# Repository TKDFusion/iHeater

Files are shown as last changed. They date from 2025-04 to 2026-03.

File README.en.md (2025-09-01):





# About the iHeater Project

iHeater is a compact and powerful solution for creating an active thermal chamber in any 3D printer. It is especially essential for printers with closed or proprietary electronics, such as those from Creality, Bambu Lab, and FlashForge, where available ports or options for connecting heaters, fans, and thermistors are often limited.

iHeater connects via USB and takes over control independently of the mainboard's limitations. Depending on the firmware used, it can operate autonomously or with full integration into Klipper.

When used in combination with bed heating, iHeater ensures uniform chamber heating-a crucial factor for printing materials like ABS, PA, PC, and other engineering plastics. The device dynamically manages heating based on the air temperature, creating stable conditions inside the chamber without overheating or temperature spikes.

Two versions are currently available:

* 100W for smaller printers (archived)
* 200W for larger printers

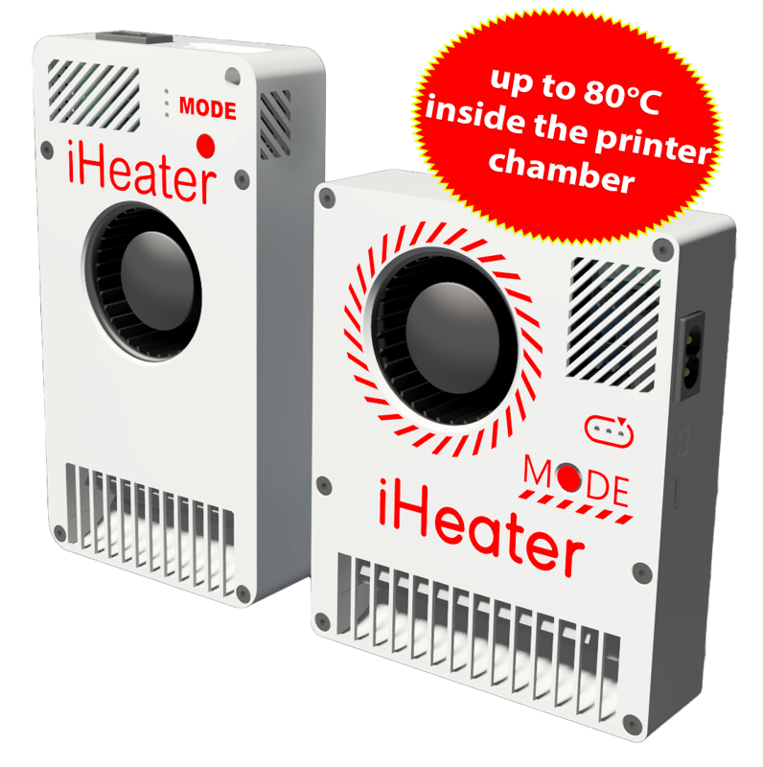
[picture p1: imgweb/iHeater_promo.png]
iHeater


**Under Klipper Control**

The board works as a separate MCU in Klipper, fully autonomously controlling the chamber heater and fan. Thanks to its 220 V power supply, iHeater does not load the printer’s power supply, which is especially important since stock PSUs often operate at their limit.

The cost of the board is comparable to or even lower than building a similar solution from a regular microcontroller, solid-state relay, and other components. Nevertheless, enthusiasts still have the option to build their own version.

iHeater is a simple way to add chamber heating to your printer to improve print quality and expand the range of materials used.

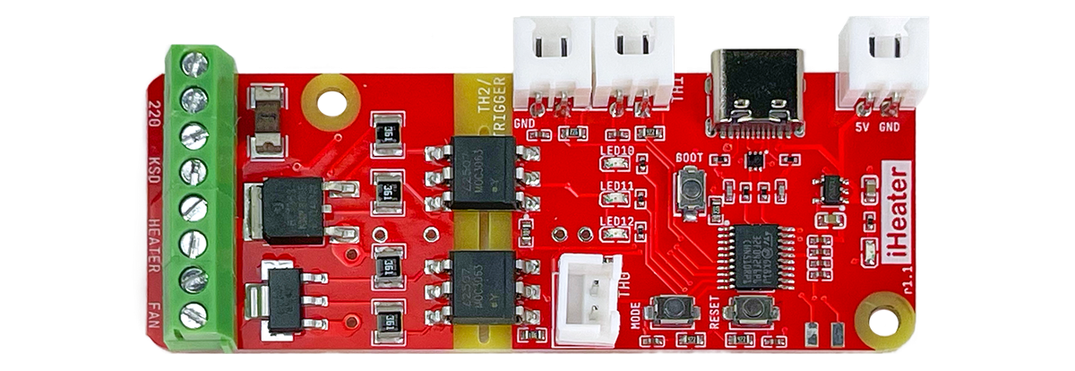
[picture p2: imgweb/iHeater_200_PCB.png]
PCB


**With iHeater Firmware**



The iHeater board is self-sufficient and includes all the necessary peripherals and interface for use as a standalone device. The desired temperature is set by sequentially pressing the MODE button, and the selected temperature is encoded and displayed using three LEDs. The increment can be changed in the firmware.

<!-- 
# iHeater Configuration for Klipper

This repository contains configuration files for the iHeater 3D printer chamber heater based on Klipper firmware and the control board of the same name. The configuration is designed to control the chamber heater and fans using the iHeater microcontroller.

## Table of Contents

- [Requirements](#requirements)
- [Preparation](#preparation)
- [Flashing Firmware to iHeater](#flashing-firmware-to-iheater)
- [Klipper Configuration](#klipper-configuration)
  - [Connecting the `iHeater` MCU](#1-connecting-the-iheater-mcu)
- [Usage](#usage)
  - [Chamber Heating Commands](#chamber-heating-commands)
  - [Automation and Control Logic](#automation-and-control-logic)
- [Notes](#notes)
- [License](#license)

## Requirements

- **Hardware:**
  - iHeater control board
  - NTC 100K 3950 thermistors (2 pcs.)
  - PTC heating element 220V 100W for the chamber
  - 7530 fan 220V for chamber air circulation
  - Thermal fuse KSD9700 or similar (220V 5A 130°C)

- **Software:**
  - Klipper (latest version)
  - A configured and running Klipper host

## Preparation

1. **Assemble the hardware:**
   - Connect the heating element and fans to the iHeater.
   - Connect the KSD to the appropriate socket.
   - Install the thermistors in the chamber and connect them to the appropriate MCU pins.
   - Make sure the pins are connected correctly according to the config file.

2. **Install the required files:**
   - Copy the `iHeater.cfg` file to the Klipper configuration directory.

## Flashing Firmware to iHeater

1. **Build the Klipper firmware for stm32f042:**

```bash
cd klipper/
make menuconfig
```

2. **In the menu, select:**

- Enable extra low-level configuration options  
- Micro-controller Architecture: STMicroelectronics STM32  
- Processor model: STM32F042  
- Bootloader offset: 8KiB bootloader  
- Clock Reference: Internal clock  
- Communication interface: USB (on PA9/PA10)

3. **Disable unnecessary options:**

```text
[*] Support GPIO "bit-banging" devices  
[ ] Support LCD devices  
[ ] Support thermocouple MAX sensors  
[ ] Support adxl accelerometers  
[ ] Support lis2dw and lis3dh 3-axis accelerometers  
[ ] Support MPU accelerometers  
[ ] Support HX711 and HX717 ADC chips  
[ ] Support ADS 1220 ADC chip  
[ ] Support ldc1612 eddy current sensor  
[ ] Support angle sensors  
[*] Support software based I2C "bit-banging"  
[ ] Support software based SPI "bit-banging"
```

4. Save and exit the menu.

5. Compile the firmware:

```bash
make clean
make
```

Expected output:

```
Creating hex file out/klipper.bin
```

6. Flash the firmware to the iHeater board:

If needed, install python3-serial:

```bash
sudo apt install python3-serial
```

**The following assumes the Katapult bootloader is installed.**

- Connect iHeater to the host in programming mode (hold the Mode button while connecting or double-press RESET).
- Find the device:

```bash
ls /dev/serial/by-id/
```

Expected result:

```
usb-katapult_stm32f042x6_0C0018000D53304347373020-if00
```

- Replace with your device ID and run:

```bash
python3 ~/katapult/scripts/flashtool.py -d /dev/serial/by-id/usb-katapult_stm32f042x6_... -f ~/klipper/out/klipper.bin
```

Expected result:

```
Flash Success
```

- Verify:

```bash
ls /dev/serial/by-id/
```

Expected:

```
usb-Klipper_stm32f042x6_...-if00
```

```text
iHeater is ready to work with Klipper
```

## Pin Configuration

| Pin  | Alias | Function |
|---|---|---|
| PA0  | TH1 | Chamber temperature sensor |
| PA1  | HEATER| Heater control |
| PA2  | FAN | Fan control |
| PA3  | TH0 | Heater temperature sensor |
| PA4  | MODE  | Mode button |
| PA5  | LED3  | LED 3 |
| PA6  | LED2  | LED 2 |
| PA7  | LED1  | LED 1 |

## Klipper Configuration

Copy the iHeater.cfg file to the folder containing printer.cfg and include it using the `[include]` directive:

```ini
[include iHeater.cfg]
```

### 1. Connecting the iHeater MCU

Edit the `iHeater.cfg` file and specify the obtained serial ID:

```ini
[mcu iHeater]
serial: usb-Klipper_stm32f042x6_0C0018000D53304347373020-if000
```

## Usage

### Chamber Heating Commands

- Set chamber temperature:

```gcode
M141 S60 ; Set chamber temp to 60°C
```

- Wait for chamber to reach temperature:

```gcode
M191 S60 ; Wait until chamber reaches 60°C
```

- Stop chamber heating:

```gcode
M141 S0  ; Disable chamber heating
```

- At the end of your slicer’s G-code, add `M141 S0` to properly shut down chamber heating.

## Notes

- **Safety:**
  - Make sure all connections are correct and safe.
  - Check that min_temp and max_temp match your hardware specs.

- **Hardware check:**
  - Test heater and fan operation before use.
  - Monitor temperature during first runs.

- **PID tuning:**
  - Perform PID tuning if precise temperature control is needed. -->

## License

This project is licensed under the MIT License. See the [LICENSE](./license.en.md) file for details.

>⚠️ **Warning: The use of heating elements and temperature control involves fire and equipment damage risk. Always follow manufacturer recommendations and observe safety precautions.

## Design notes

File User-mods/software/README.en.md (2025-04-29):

# Here is list of users software mods and articles

_Place your mod name and short description to the list below.
Please keep alphabetical ordering_

  * WSL2_Ubuntu_FF (RU) - Как прошить устройство из под Windows 10/11 используя WSL2 с работающей на ней Ubuntu 20.04 (How to flash iHeater/Katapult/Klipper firmware on Windows 10/11 using WSL2 with Ubuntu 20.04 guest OS)

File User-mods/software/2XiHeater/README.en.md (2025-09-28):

Controls two iHeaters in tandem to achieve a target chamber temperatur, adding smart LED controls:
  LEFT: Fan status
  CENTER: Target temperature set
  RIGHT: Heater active (power >30%)
I've also added logic to check if iHeater has AC power. If not, it will kill the heat up process.

Based on the original single iHeater.cfg

I tested on my SV08 MAX. LED controls are not perfect, since the SV08 MAX doesn't have the latest version of Klipper so we cannot do duplicate_pin for correct heater / fan activity indicators.
I do a 2:1 weighted average for the two chamber thermistors, one in the designated hole on the back panel, the other moves around attached to the center of the gantry...
Please refer to my video on YouTube for my arrangement of the two iHeaters: https://www.youtube.com/watch?v=KfKujRUKnWg

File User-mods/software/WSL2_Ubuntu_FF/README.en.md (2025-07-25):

# How to Flash a Device on Windows 10/11 Using WSL2 with Ubuntu 20.04

## Steps 1-10 are suitable for flashing:

* Standalone Firmware
* Katapult Bootloader (for later flashing of the Klipper runtime from the printer host)
* Klipper runtime without using Katapult

It is assumed the firmware is already compiled and located on the WSL guest system at `~/iHeater/firmware.bin`

> [!NOTE] At the beginning of each step, brackets indicate where to perform the action: [WIN] - in native Windows, [WSL] - in the guest OS terminal (Ubuntu)

1. **[WIN]** Follow [this guide](https://learn.microsoft.com/en-us/windows/wsl/connect-usb) to install USBIPD-WIN from the [releases page](https://github.com/dorssel/usbipd-win/releases)

2. **[WSL]** Ensure WSL is active (simply start a command-line session in the guest OS)

3. **[WIN]** Connect the device to the PC (ensure the BOOT jumper is installed during connection)

   > [!NOTE] Note that a clean chip (never previously flashed) automatically enters DFU mode without a jumper.

4. **[WIN]** Open Windows PowerShell **as administrator** and enter:

    ```
    > usbipd list
    BUSID  VID:PID    DEVICE                                                        STATE
    5-2    0483:df11  STM32  BOOTLOADER                                             Not shared
    ```

   Remember the BUSID value

5. **[WIN]** Enter the command with the recorded BUSID

   > [!NOTE] This command is necessary if the last column shows `Not shared` (e.g., after flashing Klipper)

   ```
   > usbipd bind --busid 5-2
   ```

   Repeat the command from step 4 to confirm the STATE column shows "Shared"

   ```
   > usbipd list
   Connected:
   BUSID  VID:PID    DEVICE                                                        STATE
   5-2    0483:df11  STM32  BOOTLOADER                                             Shared
   ```

6. **[WIN]** Attach the device to the guest OS (replace `busid` with your actual value):

   ```
   > usbipd attach --wsl --busid 5-2
   ```

   > [!NOTE] This command must be run each time the device is reconnected/rebooted, but can be executed from PowerShell without administrator rights

   The device will then "disconnect" from Windows and attach to the guest OS.

   Verify the device is attached using the command from step 4 (STATE should be `Attached`)

   ```
   > usbipd list
   Connected:
   BUSID  VID:PID    DEVICE                                                        STATE
   5-2    0483:df11  STM32  BOOTLOADER                                             Attached
   ```

7. **[WSL]** In the guest OS, verify device presence with:

   ```
   > lsusb
   Bus 001 Device 006: ID 0483:df11 STMicroelectronics STM Device in DFU Mode
   ```

8. **[WSL]** Install the utility in the guest OS

   ```
   > sudo apt install dfu-util
   ```

9. **[WSL]** Ensure the board is in DFU mode and visible to dfu-util:

   ```
   > sudo dfu-util --list
   ```

10. **[WSL]** Flash the firmware

    ```
    > sudo dfu-util -a 0 -s 0x08000000 -D ~/iHeater/firmware.bin
    ```

## Further Steps - If You Wish to Compile and Flash the Klipper Runtime from WSL (Instead of the Printer Host)

Assuming the firmware is already compiled (as per the official guide) and located at `~/iHeater/klipper.bin`

11. **[WIN]** Reconnect the device (unplug/plug USB) while holding the MODE button. LED3 should start blinking slowly, indicating Katapult is ready to receive the firmware. Release the button.

12. **[WIN]+** **[WSL]** Repeat steps 4-7 (step 5 can likely be skipped—see note therein). The command in step 7 should now show:

    ```
    > lsusb
    Bus 001 Device 005: ID 1d50:6177 OpenMoko, Inc. stm32f042x6
    ```

    This indicates the device name has changed.

13. **[WSL]** The command `ls /dev/serial/by-id/` may return nothing, since the connected board appears as a standard USB-CDC-ACM device.

    To verify, use:

    ```
    > dmesg
    ```

    **Note - In the example, the last line shows "ttyACM0" - this is the device "address".**

14. **[WSL]** Flash the device (with sudo). Ensure paths are correct:

    ```
    > sudo python3 ~/katapult/scripts/flashtool.py -d /dev/ttyACM0 -b 250000 -f ~/iHeater/klipper.bin
    ```

That’s it - you can now connect the board to the printer and proceed with configuration per the documentation.

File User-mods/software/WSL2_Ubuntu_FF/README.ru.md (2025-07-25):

# WSL

## Как прошить устройство из под Windows 10/11 используя WSL2 с работающей на ней Ubuntu 20.04

## Пункты 1-10 подходят для прошивки:
- Standalone Firmware
- Загрузчика Katapult (для последующей заливки управляемой части Klipper уже с хоста самого принтера)
- Управляемой части Klipper без использования Katapult

Предполагается что прошивка уже скомпилирована и находится на гостевой системе WSL по пути `~/iHeater/firmware.bin`

> [!NOTE] В начале каждого пункта в квадратных скобках указано где именно проводить указанные действия: [WIN] - в самом Windows, [WSL] - в терминале гостевой ОС (Ubuntu)

1. **[WIN]** Следуя вот [этой инструкции](https://learn.microsoft.com/en-us/windows/wsl/connect-usb) установить USBIPD-WIN со [страницы релизов](https://github.com/dorssel/usbipd-win/releases)

2. **[WSL]** Убедиться что WSL активен (достаточно просто запустить сеанс командной строки гостевой ОС)

3. **[WIN]** Подключаем устройство к ПК (убедитесь что при подключении установлена перемычка BOOT)

    > [!NOTE] Обратите внимание, что чистый чип (ранее не прошивавшийся) автоматически переходит в режим DFU без перемычки.

4. **[WIN]** Открываем Windows PowerShell **в режиме администратора** и вводим

    ```
    > usbipd list
    BUSID  VID:PID    DEVICE                                                        STATE
    5-2    0483:df11  STM32  BOOTLOADER                                             Not shared
    ```
    Запоминаем значение в колоке BUSID

5. **[WIN]** Вводим команду с подстановкой запомненного BUSID

    > [!NOTE] Эта команда нужна в том случае, если в последнем столбце появляется `Not shared` (например после прошивки клиппера)

    ```
    > usbipd bind --busid 5-2
    ```

    повторяем команду из п.4 чтобы убедиться что в столбце STATE для нашего устройства указано "Shared"

    ```
    > usbipd list
    Connected:
    BUSID  VID:PID    DEVICE                                                        STATE
    5-2    0483:df11  STM32  BOOTLOADER                                             Shared
    ```

6. **[WIN]** Прицепляем устройство в гостевую ОС (не забываем заменить значение для `busid` на свой):

    ```
    > usbipd attach --wsl --busid 5-2
    ```
    > [!NOTE]Данную команду данную комманду нужно вводить каждый раз, когда переподключаете/перезагружаете устройство, но делать это уже можно в Power Shell без прав администратора

    При этом устройство "отключиться" от Windows и подключится внутрь гостевой ОС.

    Проверяем что устройство прицепилось используя команду из п.4 (в столбце STATE должно быть написано `Attached`)

    ```
    > usbipd list
    Connected:
    BUSID  VID:PID    DEVICE                                                        STATE
    5-2    0483:df11  STM32  BOOTLOADER                                             Attached
    ```

7. **[WSL]** В гостевой ОС проверяем наличие устройства командой `lsusb`

    ```
    > lsusb
    Bus 001 Device 006: ID 0483:df11 STMicroelectronics STM Device in DFU Mode
    ```

8. **[WSL]** Устанавливаем на гостевую ОС утилиту

    ```
    > sudo apt install dfu-util
    ```

9. **[WSL]** Убедитесь что подключенная плата в режиме DFU и dfu-util ее видит (в квадратных скобках будет идентификатор устройства, который было видно так же в пп.4-7)

    ```
    > sudo dfu-util --list

    dfu-util 0.9

    Copyright 2005-2009 Weston Schmidt, Harald Welte and OpenMoko Inc.
    Copyright 2010-2016 Tormod Volden and Stefan Schmidt
    This program is Free Software and has ABSOLUTELY NO WARRANTY
    Please report bugs to http://sourceforge.net/p/dfu-util/tickets/

    Found DFU: [0483:df11] ver=2200, devnum=10, cfg=1, intf=0, path="1-1", alt=1, name="@Option Bytes  /0x1FFFF800/01*016 e", serial="FFFFFFFEFFFF"
    Found DFU: [0483:df11] ver=2200, devnum=10, cfg=1, intf=0, path="1-1", alt=0, name="@Internal Flash  /0x08000000/032*0001Kg", serial="FFFFFFFEFFFF"
    ```

10. **[WSL]** Прошиваем

    ```
    > sudo dfu-util -a 0 -s 0x08000000 -D ~/iHeater/firmware.bin

    dfu-util 0.9

    Copyright 2005-2009 Weston Schmidt, Harald Welte and OpenMoko Inc.
    Copyright 2010-2016 Tormod Volden and Stefan Schmidt
    This program is Free Software and has ABSOLUTELY NO WARRANTY
    Please report bugs to http://sourceforge.net/p/dfu-util/tickets/

    dfu-util: Invalid DFU suffix signature
    dfu-util: A valid DFU suffix will be required in a future dfu-util release!!!
    Opening DFU capable USB device...
    ID 0483:df11
    Run-time device DFU version 011a
    Claiming USB DFU Interface...
    Setting Alternate Setting #0 ...
    Determining device status: state = dfuERROR, status = 10
    dfuERROR, clearing status
    Determining device status: state = dfuIDLE, status = 0
    dfuIDLE, continuing
    DFU mode device DFU version 011a
    Device returned transfer size 2048
    DfuSe interface name: "Internal Flash  "
    Downloading to address = 0x08000000, size = 24252
    Download        [=========================] 100%        24252 bytes
    Download done.
    File downloaded successfully
    ```

## Следующие шаги - если хочется скомпилировать и прошить управляемую часть Klipper также из под WSL (то есть не с хоста принтера).

Допустим вы скомпилировали уже прошивку (согласно инструкции в документации) и теперь она у вас лежит в `~/iHeater/klipper.bin`

11. **[WIN]** Переподключаем устройство к ПК (USB-шнурок отключить-поодключить) с зажатой кнопкой MODE .
При этом должен начать медленно мигать LED3 - это значит что Katapult перешла в режим ожидания получения прошивки (аналог DFU-режима) и кнопку можно отпустить.

12. **[WIN]**+**[WSL]** Повторяем пп.4-7 (п.5 скорее всего можно пропустить - см. в нем пояснения)
при этом команда из п.7 покажет что-то вроде:

    ```
    > lsusb
    Bus 001 Device 005: ID 1d50:6177 OpenMoko, Inc. stm32f042x6
    ```
    То есть название устройства изменилось.

13. **[WSL]** В WSL команда ls /dev/serial/by-id/ скорее всего не даст результата, так как подключенная плата появится там в виде стандартного устройства USB-CDC-ACM

    Проверить это можно введя команду
    ```
    > dmesg

    [53229.047396] vhci_hcd vhci_hcd.0: pdev(0) rhport(0) sockfd(3)
    [53229.048526] vhci_hcd vhci_hcd.0: devid(327682) speed(2) speed_str(full-speed)
    [53229.049243] vhci_hcd vhci_hcd.0: Device attached
    [53229.321619] vhci_hcd: vhci_device speed not set
    [53229.391684] usb 1-1: new full-speed USB device number 7 using vhci_hcd
    [53229.471650] vhci_hcd: vhci_device speed not set
    [53229.541609] usb 1-1: SetAddress Request (7) to port 0
    [53229.579674] usb 1-1: New USB device found, idVendor=1d50, idProduct=6177, bcdDevice= 1.00
    [53229.580696] usb 1-1: New USB device strings: Mfr=1, Product=2, SerialNumber=3
    [53229.581508] usb 1-1: Product: stm32f042x6
    [53229.581982] usb 1-1: Manufacturer: katapult
    [53229.582912] usb 1-1: SerialNumber: 460024000E53304347373020
    [53229.586466] cdc_acm 1-1:1.0: ttyACM0: USB ACM device
    ```
    
    **Обратите внимание - в примере в последней строчке указан "ttyACM0" - это и есть "адрес" устройства.**

14. **[WSL]** Прошиваем устройство (под sudoб то есть правами суперпользователя)
не забываем проверить и при необходимости поправить пути

    ```
    > sudo python3 ~/katapult/scripts/flashtool.py -d /dev/ttyACM0 -b 250000 -f ~/iHeater/klipper.bin

    Connecting to Serial Device /dev/ttyACM0, baud 250000
    Detected USB device running Katapult
    Detected Klipper binary version v0.13.0-51-gbfda326c2, MCU: stm32f042x6
    Attempting to connect to bootloader
    Katapult Connected
    Software Version: v0.0.1-96-gbc1ecea
    Protocol Version: 1.1.0
    Block Size: 64 bytes
    Application Start: 0x8002000
    MCU type: stm32f042x6
    Flashing '/home/kekht/iHeater/klipper_vanilla/klipper.bin'...

    [##################################################]

    Write complete: 14 pages
    Verifying (block count = 213)...

    [##################################################]

    Verification Complete: SHA = 3C7153502764CB6C948E9FD7872F69B2D0CBED55
    Programming Complete
    ```

Вот и все, теперь можно подключать к принтеру и настраивать согласно документации.

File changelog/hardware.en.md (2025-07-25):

Rev 1.1

- Добавлен третий термистор - используется как триггер включения iHeater: нагрев включается при температуре выше 60 °C, отключается при снижении температуры стола до устойчиво низкого уровня. Реализовано в поддержку пользователей Standalone-прошивки.

- Обновлена топология платы - улучшено размещение компонентов и трассировка.

- Изменён способ подключения питания - основной вариант: кабель питания вводится через кабельный ввод в стенке корпуса и подключается в винтовые клеммы. Позволяет делать удобный монтаж с коммутацией питания через основную линию питания принтера. Альтернативный способ: разъём C8 устанавливается на корпус. Плату можно ориентировать произвольно.

- Pin to pin совместимо с текущей версией кроме поддержки третьего термистора.

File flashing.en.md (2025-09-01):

# Firmware

This document provides instructions for building and flashing the **Katapult** bootloader for the **iHeater** microcontroller. The Katapult bootloader enables flashing Klipper firmware via USB and includes guidance on flashing **Klipper** firmware onto the **iHeater** controller.

---

## Requirements

* STM32F042F6P6
* iHeater board
* USB cable
* Linux system (e.g., Raspberry Pi or 3D printer)

!!! warning "If you cannot build and flash firmware on the printer"
    [Refer to the WSL section](./User-mods/software/WSL2_Ubuntu_FF/README.en.md)

---

## Building Katapult

1. Clone the Katapult repository:

```bash
git clone https://github.com/Arksine/katapult.git
cd katapult
make menuconfig
```

2. In `menuconfig`, select:

<!-- - MCU Architecture: STM32
- Processor model: STM32F042
- Clock Reference: Internal
- Communication interface: USB (on PA9/PA10)
- Application start offset: **8KiB offset**
- [x] Support bootloader entry on rapid double click of reset button
- [x] Enable bootloader entry on button (or gpio) state
- (!PA4)  Button GPIO Pin
- [X] Enable Status LED
- (PA5)   Status LED GPIO Pin -->

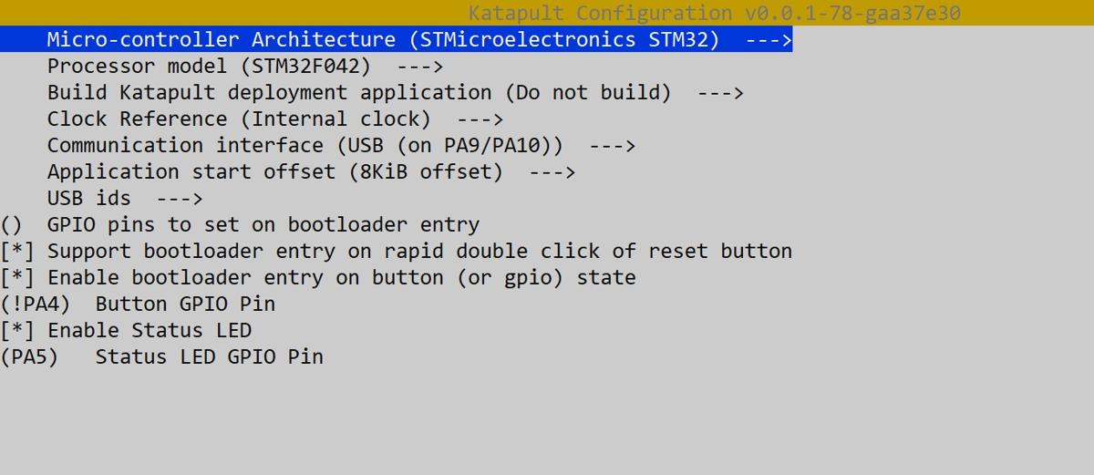
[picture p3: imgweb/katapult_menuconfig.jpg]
menuconfig


3. Build the firmware:

```bash
make
```

The firmware will be created in `out/katapult.bin`.

---

## Flashing Katapult via DFU

> This step is only needed once to install Katapult.

### Preparation:

Install `dfu-util` if it is not already installed:

```bash
sudo apt install dfu-util
```

According to the board version:

=== "r1"

    Set the jumper to BOOT0 and power cycle the board (or press the RESET button).
    The microcontroller will boot into DFU mode.

=== "r1.1"

    Press and hold BOOT, then power cycle the board (or press the RESET button), and release BOOT.
    The microcontroller will boot into DFU mode.

Check the connection:

```bash
lsusb
```

You should see:

```
ID 0483:df11 STMicroelectronics STM Device in DFU Mode
```

### Flash Katapult:

Put it in DFU mode.

Run the command:

```bash
dfu-util -a 0 -D out/katapult.bin -s 0x08000000:leave
```

Example of successful flashing:

```
Downloading to address = 0x08000000, size = 4968
Download        [=========================] 100%         4968 bytes
Download done.
File downloaded successfully
Transitioning to dfuMANIFEST state
```

Exit DFU mode.

After reboot:

```bash
ls /dev/serial/by-id/*
```

You should see:

```
/dev/serial/by-id/usb-katapult_stm32f042x6_XXXXXXXXXXXXXX-if00
```

If there are permission issues when flashing, run:

```bash
sudo chmod 777 /dev/serial/by-id/usb-katapult_stm32f042x6_XXXXXXXXXXXXXX-if00
```

!!! warning "if something went wrong"
    erase the memory of the MCU and repeat the previous steps
    ```
    touch /tmp/empty.bin
    ```
    ```
    dfu-util -a 0 -d 0483:df11 -s :mass-erase:force -D /tmp/empty.bin
    ```

### Notes

* Katapult uses the first 8 KiB of flash, so **set 8 KiB bootloader offset in Klipper**.
* DFU mode can be entered using either a double Reset or a button on GPIO (PA4).
* If PA13/PA14 are used for SWD.
* Once Katapult is flashed, ST-Link is no longer needed - all further work is done via USB.

---

## Flashing Klipper to iHeater

### Compile the firmware:

```bash
cd ~/klipper
```

```
make menuconfig
```

#### In the menu, select:

```
Enable extra low-level configuration options

Micro-controller Architecture (STMicroelectronics STM32)

Processor model (STM32F042)

Bootloader offset (8KiB bootloader)

Clock Reference (Internal clock)

Communication interface (USB (on PA9/PA10))
```

#### Disable all unnecessary options:

```
[*] Support micro-controller based ADC (analog to digital)
[ ] Support communicating with external chips via SPI bus
[ ] Support communicating with external chips via I2C bus
[*] Support GPIO based button reading
[ ] Support Trinamic stepper motor driver UART communication
[ ] Support 'neopixel' type LED control
[ ] Support measuring fan tachometer GPIO pins
    *** LCD chips ***
[ ] Support ST7920 LCD display
[ ] Support HD44780 LCD display
    *** External ADC type chips ***
[ ] Support HX711 and HX717 ADC chips
```

#### Save and exit the menu.

#### Build the firmware:

```bash
make clean
make
```

!!! Result should look like:
    Creating hex file out/klipper.bin

### Flash firmware to the iHeater board

!!! note "Install python3-serial if needed"
    sudo apt install python3-serial

**The following assumes Katapult bootloader is already installed**

* Connect the iHeater to the host in programming mode (hold the MODE button during connection or double-press RESET).

* List serial devices:

```bash
ls /dev/serial/by-id/
```

Example output:

```
usb-katapult_stm32f042x6_0C0018000D53304347373020-if00
```

* Install flashtool if needed:

```bash
pip install flashtool
```

* Replace the ID with your actual ID and run:

```bash
python3 ~/katapult/scripts/flashtool.py -d /dev/serial/by-id/usb-katapult_stm32f042x6_0C0018000D53304347373020-if00 -f ~/klipper/out/klipper.bin
```

Expected output:

```
Flashing '/home/pi/klipper/out/klipper.bin'...

[##################################################]

Write complete: 20 pages

Verifying (block count = 319)...

[##################################################]

Verification Complete: SHA = 8A3DDF39A0E70B684DC6BAF74EF8F089EBDD6C18

Flash Success
```

* Verify:

```bash
ls /dev/serial/by-id/
```

Expected output:

```
usb-Klipper_stm32f042x6_0C0018000D53304347373020-if00
```

`iHeater is ready to work with Klipper`

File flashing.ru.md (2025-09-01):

#  Прошивка

Этот документ содержит инструкции по сборке и прошивке загрузчика **Katapult** для микроконтроллера **iHeater**. Загрузчик Katapult позволяет прошивать прошивку Klipper по USB, а так же содержит документацию по установке прошивки **Klipper** на контроллер **iHeater** 

---

## Что потребуется

- STM32F042F6P6
- Плата iHeater
- USB кабель
- Linux-система (например, Raspberry Pi или принтер)

!!! warning "Если нет возможности собрать и прошить прошивку на принтере"
    [Обратитесь к разделу WSL](../iHeater/User-mods/software/WSL2_Ubuntu_FF/README.ru.md)

---

## Сборка Katapult

1. Клонировать репозиторий Katapult:

```bash
git clone https://github.com/Arksine/katapult.git
```
```
cd katapult
```
```
make menuconfig
```

2. В `menuconfig` выбрать:

menuconfig

3. Сборка:

```bash
make
```

Прошивка будет создана в `out/katapult.bin`.

---

## Прошивка Katapult через DFU

> Этот шаг нужен только один раз, для загрузки самого Katapult.

### Подготовка:
Устновить утилиту dfu-util, если она ещё не установлена:
    
    sudo apt install dfu-util

В соответствии с версией платы:

=== "r1"

    Установить джампер на BOOT0 и перезапустить питание платы (или нажать кнопку RESET).
    Микроконтроллер загрузится в режим DFU.

=== "r1.1"

    Нажать кнопку BOOT и перезапустить питание платы (или нажми кнопку RESET) отпустить BOOT.
    Микроконтроллер загрузится в режим DFU.

Проверить подключение:

    lsusb

Результат:

    ID 0483:df11 STMicroelectronics STM Device in DFU Mode

### Прошивка Katapult:
Перевести в режим DFU.

Выполнить команду:

```
dfu-util -a 0 -D out/katapult.bin -s 0x08000000:leave
```

Пример успешной прошивки:

```
Downloading to address = 0x08000000, size = 4968
Download        [=========================] 100%         4968 bytes
Download done.
File downloaded successfully
Transitioning to dfuMANIFEST state
```

Выйти из режима DFU.

После перезапуска 
```
ls /dev/serial/by-id/*
```
Результат:
```
/dev/serial/by-id/usb-katapult_stm32f042x6_XXXXXXXXXXXXXX-if00
```

Если нет прав, возможны ошибки при прошивке, чтобы получить доступ выполнить команду:
```
sudo chmod 777 /dev/serial/by-id/usb-katapult_stm32f042x6_XXXXXXXXXXXXXX-if00
``` 

!!! warning "если что-то пошло не так"
    затрите память МК и повторите предыдущие шаги
    ```
    touch /tmp/empty.bin
    ```
    ```
    dfu-util -a 0 -d 0483:df11 -s :mass-erase:force -D /tmp/empty.bin
    ```

### Примечания

- Katapult занимает первые 8 КБ Flash, поэтому **в Klipper обязательно указывать смещение 8 KiB**.
- Можно использовать либо двойной Reset, либо кнопку на GPIO (PA4) для входа в DFU.
- Если PA13/PA14 используются для SWD
- После прошивки Katapult можно больше не использовать ST-Link - вся дальнейшая работа по USB.

## Установка прошивки на iHeater

### Компиляция прошивки
```
cd ~/klipper
```
```
make menuconfig
```

#### В меню конфигурации выбрать
```
Enable extra low-level configuration options

Micro-controller Architecture (STMicroelectronics STM32)

Processor model (STM32F042)

Bootloader offset (8KiB bootloader)

Clock Reference (Internal clock)

Communication interface (USB (on PA9/PA10))
```
#### Выключить все лишнее
```
[*] Support micro-controller based ADC (analog to digital)
[ ] Support communicating with external chips via SPI bus
[ ] Support communicating with external chips via I2C bus
[*] Support GPIO based button reading
[ ] Support Trinamic stepper motor driver UART communication
[ ] Support 'neopixel' type LED control
[ ] Support measuring fan tachometer GPIO pins
    *** LCD chips ***
[ ] Support ST7920 LCD display
[ ] Support HD44780 LCD display
    *** External ADC type chips ***
[ ] Support HX711 and HX717 ADC chips
```

#### Сохранить и выйти из меню.

#### Скомпилировать прошивку
```
make clean
```
```
make
```

Результат:

    Creating hex file out/klipper.bin

### Установка прошивки на плату iHeater

!!! note "Может потребоваться установка python3-serial"
    
    sudo apt install python3-serial

**Далее рассматривается вариант установки с установленным бутлоадером Katapult**

- Подключить iHeater к хосту в режиме программирования (удерживая кнопку Mode при подключении или дважды нажав RESET).

- Выполнить поиск 
    ```
    ls /dev/serial/by-id/
    ```
    Результат должен выглядеть так:

    ```
    usb-katapult_stm32f042x6_0C0018000D53304347373020-if00
    ```

    - При необходимости установить flashtool

    ```
    pip install flashtool
    ```

- Изменить на свой ID и введите:
    
        python3 ~/katapult/scripts/flashtool.py -d /dev/serial/by-id/usb-katapult_stm32f042x6_0C0018000D53304347373020-if00 -f ~/klipper/out/klipper.bin

    Результат:

        Flashing '/home/pi/klipper/out/klipper.bin'...

        [##################################################]
        
        Write complete: 20 pages
        
        Verifying (block count = 319)...
        
        [##################################################]
        
        Verification Complete: SHA = 8A3DDF39A0E70B684DC6BAF74EF8F089EBDD6C18
        
        Flash Success

- Проверить: 
    ```        
    ls /dev/serial/by-id/
    ```
    Результат:

        usb-Klipper_stm32f042x6_0C0018000D53304347373020-if00

    ```iHeater готов для работы с Klipper```

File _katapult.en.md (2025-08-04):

# Firmware

This document provides instructions for building and flashing the **Katapult** bootloader for the **iHeater** microcontroller. Katapult allows firmware updates for Klipper via USB, and also includes guidance for installing **Klipper** firmware onto the **iHeater** controller.

---

## Requirements

* STM32F042F6P6
* iHeater board
* ST-Link V2 programmer (for the initial flash) or USB cable
* Linux system (e.g., Raspberry Pi or printer)

!!! warning "If you're unable to compile and flash firmware directly on the printer"
[Refer to the WSL section](../../User-mods/software/WSL2_Ubuntu_FF/README.ru.md)

---

## Building Katapult

1. Clone the Katapult repository:

```bash
git clone https://github.com/Arksine/katapult.git
```

```bash
cd katapult
```

```bash
make menuconfig
```

2. In `menuconfig`, choose:

* MCU Architecture: STM32
* Processor model: STM32F042
* Clock Reference: Internal
* Communication interface: USB (on PA9/PA10)
* Application start offset: **8KiB offset**
* [x] Support bootloader entry on rapid double click of reset button
* [x] Enable bootloader entry on button (or gpio) state
* (!PA4)  Button GPIO Pin
* [x] Enable Status LED
* (PA5)   Status LED GPIO Pin

menuconfig

3. Build:

```bash
make
```

The firmware will be generated in `out/katapult.bin`.

---

## Flashing Katapult via DFU

> This step is required only once to load the Katapult bootloader.

### Preparation:

Install dfu-util if it's not already installed:

```bash
sudo apt install dfu-util
```

Set the BOOT0 jumper and power cycle the board (or press RESET).
The microcontroller will enter DFU mode.

Check the connection:

```bash
lsusb
```

You should see:

```text
ID 0483:df11 STMicroelectronics STM Device in DFU Mode
```

### Flashing Katapult:

Execute:

```bash
dfu-util -a 0 -D out/katapult.bin -s 0x08000000:leave
```

Successful flash output:

```
Downloading to address = 0x08000000, size = 4968
Download        [=========================] 100%         4968 bytes
Download done.
File downloaded successfully
Transitioning to dfuMANIFEST state
```

Remove the jumper, hold the MODE button, press and release RESET (or replug USB).

After reboot:

```bash
ls /dev/serial/by-id/*
```

You should see:

```bash
/dev/serial/by-id/usb-katapult_stm32f042x6_XXXXXXXXXXXXXX-if00
```

If you encounter permission errors:

```bash
sudo chmod 777 /dev/serial/by-id/usb-katapult_stm32f042x6_XXXXXXXXXXXXXX-if00
```

### Notes

* Katapult occupies the first 8KB of Flash, so **8KiB offset must be specified in Klipper**.
* You can enter DFU using either double reset or a GPIO button (PA4).
* PA13/PA14 are used for SWD.
* After Katapult is flashed, ST-Link is no longer needed; future updates can be done via USB.

## Installing Firmware to iHeater

### Compiling Firmware

```bash
cd klipper/
```

```bash
make menuconfig
```

#### In the configuration menu select:

```
Enable extra low-level configuration options

Micro-controller Architecture (STMicroelectronics STM32)

Processor model (STM32F042)

Bootloader offset (8KiB bootloader)

Clock Reference (Internal clock)

Communication interface (USB (on PA9/PA10))
```

#### Disable all unused options:

```
[*] Support micro-controller based ADC (analog to digital)
[ ] Support communicating with external chips via SPI bus
[ ] Support communicating with external chips via I2C bus
[*] Support GPIO based button reading
[ ] Support Trinamic stepper motor driver UART communication
[ ] Support 'neopixel' type LED control
[ ] Support measuring fan tachometer GPIO pins
    *** LCD chips ***
[ ] Support ST7920 LCD display
[ ] Support HD44780 LCD display
    *** External ADC type chips ***
[ ] Support HX711 and HX717 ADC chips
```

#### Save and exit the menu.

#### Compile the firmware

```bash
make clean
```

```bash
make
```

!!! The output should be:

```
Creating hex file out/klipper.bin
```

### Installing Firmware to iHeater Board

!!! note "Install python3-serial if needed"

```bash
sudo apt install python3-serial
```

**The following steps assume Katapult bootloader is already installed**

* Connect iHeater to the host in programming mode (hold Mode while plugging in USB or double press RESET).

* Find the device:

```bash
ls /dev/serial/by-id/
```

You should see something like:

```
usb-katapult_stm32f042x6_0C0018000D53304347373020-if00
```

* Install flashtool if needed:

```bash
pip install flashtool
```

* Replace with your device ID and run:

```bash
python3 ~/katapult/scripts/flashtool.py -d /dev/serial/by-id/usb-katapult_stm32f042x6_0C0018000D53304347373020-if00 -f ~/klipper/out/klipper.bin
```

Expected output:

```
Flashing '/home/pi/klipper/out/klipper.bin'...

[##################################################]

Write complete: 20 pages

Verifying (block count = 319)...

[##################################################]

Verification Complete: SHA = 8A3DDF39A0E70B684DC6BAF74EF8F089EBDD6C18

Flash Success
```

* Verify:

```bash
ls /dev/serial/by-id/
```

Output should be:

```
usb-Klipper_stm32f042x6_0C0018000D53304347373020-if00
```

`iHeater is now ready for use with Klipper`

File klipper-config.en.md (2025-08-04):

### iHeater Configuration for Klipper

This section contains configuration files for the iHeater chamber heater for 3D printers running the Klipper firmware. The configuration is designed to manage chamber heating and fans using the iHeater control board.

### Requirements

#### Hardware

* iHeater control board
* NTC 100K 3950 thermistors (2 pcs)
* PTC heating element 220V 100W, for the chamber
* 7530 220V fan, for air circulation inside the chamber
* Thermal fuse KSD9700 or similar (220V 5A 130°C)

#### Software

* Klipper (latest version)
* Configured and running Klipper host

### Klipper Configuration

Copy the `iHeater.cfg` configuration file into your `printer.cfg` directory(it could be /klipper_config) and include it using the `[include]` directive:

```bash
cd ~/klipper_config
```

```bash
wget https://raw.githubusercontent.com/pavluchenkor/iHeater/refs/heads/main/iHeater.cfg
```

### Connecting the iHeater MCU

Edit `iHeater.cfg` and specify the serial ID of your board:

```ini
[mcu iHeater]
serial: usb-Klipper_stm32f042x6_ХХХХХХХХХХХХХХХХХХХХХХХ-ХХХХ
```

## Preparation for Use

The configuration file includes the following section:

```ini
[gcode_macro CHAMBER_VARS]
variable_chamber_target: 0          # Target chamber temperature, °C
variable_start_offset: 10           # Chamber temperature sufficient for starting the print, °C
variable_delta_temp: 10             # Difference between chamber temperature and heater temperature, °C
variable_min_heater_temp: 50        # Minimum heater temperature (for cooling), °C
variable_max_heater_temp: 100       # Maximum heater temperature, °C
variable_control_interval: 1.0      # Control function call interval, seconds
variable_air_min_delta: 0.5         # Minimum difference between target and current chamber temperature (heater = target + delta_temp), °C
variable_air_max_delta: 5.0         # Maximum difference between target and current chamber temperature (heater = max_heater_temp), °C
gcode:
```

**The maximum allowable heater temperature depends on the enclosure material.**

To verify:

!. Set the heated bed to 95-100°C
1. Set the heater temperature to 100 °C using the Fluidd or Mainsail interface.
2. Ensure the iHeater is inside the printer's enclosed volume.
3. After reaching the set temperature, inspect areas where the heater contacts plastic parts of the enclosure. Plastic should not soften.
4. Increase the temperature by 5-10 °C and repeat the inspection.
5. Continue repeating this procedure until the maximum allowable heater temperature is identified without risking enclosure deformation.

This approach helps determine a safe maximum temperature and achieves optimal efficiency for the iHeater operation.

## Usage

### Chamber Heater Control Commands

* Setting the chamber temperature:

  ```
    M141 S60  ; Sets the chamber temperature to 60°C
  ```

* Waiting for the chamber to reach temperature:

  ```
    M191 S60  ; Waits until the chamber temperature reaches 60°C
  ```

* Turning off the chamber heater:

  ```
    iHEATER_OFF   ; Turns off the chamber heater
  ```

* At the end of your slicer's G-code, add `iHEATER_OFF` to correctly disable the chamber heating.

### Start G-code

Modern 3D slicers support the automatic activation of an active heated chamber during G-code generation for printing. To enable this, specify the chamber temperature in the filament properties. If the slicer lacks this functionality, you must manually add a command to enable chamber heating in the start G-code.

Procedure:

* Set the target chamber temperature.
* Activate bed heating to efficiently and quickly heat the chamber.
* Continue with the standard printing start G-code.

Example start G-code:

```
; --- Start of print start G-code ---

; ****** iHeater Start ******
M141 S60       ; Set chamber temperature to 60°C
; ****** iHeater End ******

; --- Remaining start G-code ---
; Activate bed heating
...
```

!!! warning "To ensure proper completion of the iHeater control macro, add the iHEATER_OFF command to the printer's end G-code."

```
; --- Start of print end G-code ---

; ****** iHeater Start ******
iHEATER_OFF
; ****** iHeater End ******

; --- Remaining end G-code ---
...
```

## Disable
To disable iHeater, you need to comment out the line [include iHeater.cfg] in the printer.cfg file:

```
# [include iHeater.cfg]
```
and remove the corresponding lines from the start and end G-code.

### Notes

* **Safety:**

  * Ensure all wiring is done properly and safely.
  * Verify that `min_temp` and `max_temp` values align with hardware specs.

* **Hardware Check:**

  * Test heater and fan functionality before use.
  * Monitor temperature during the initial runs.

* **PID Tuning:**

  * Perform PID calibration if precise temperature control is required.

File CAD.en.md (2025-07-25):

## iHeater CAD Files

This directory contains 3D models for the enclosure and mounting components of the iHeater device.

### File List for iHeater 100W

| File | Description |
| --- | --- |
| [`Base.stl`](CAD/Base.stl) | The base of the enclosure where all components are mounted |
| [`Cover Two Color.stl`](CAD/Cover%20Two%20Color.stl) | Top cover designed for dual-color printing |
| [`Cover.stl`](CAD/Cover.stl) | Standard top cover |
| [`iHeater.stp`](CAD/iHeater.stp) | Complete assembly in STEP format (for CAD software) |

### File List for iHeater 200W

| File | Description |
|---|---|
| [`iHeater_Base_200W.stl`](CAD/iHeater_Base_200W.stl) | The base of the enclosure where all components are mounted |
| [`iHeater_Top_Cover_200_W_two_Color.stl`](CAD/iHeater_Top_Cover_200_W_two_Color.stl)|Top cover designed for dual-color printing|
| [`iHeater_Top_Cover_200W.stl`](CAD/iHeater_Top_Cover_200W.stl) | Standard top cover|
| [`iHeater.stp`](CAD/iHeater200W.stp)| Complete assembly in STEP format (for CAD software)|
| [`iHeater_2.0.0.stp`](CAD/iHeater_2.0.0.stp) | Alternative design. Complete assembly in STEP format (for CAD software) |

### File list for iHeater 200W r1.1 PCB

| File | Description |
| --- | --- |
| [`iHeater_Base_200W_r1.1.stl`](CAD/iHeater_Base_200W_r1.1.stl) | Housing base to which all components are attached  |
| [`iHeater_Top_Cover_200W_r1.1_color.stl`](CAD/iHeater_Top_Cover_200W_r1.1_color.stl) | Top cover printed in two colors|
| [`iHeater_Top_Cover_200W_r1.1.stl`](CAD/iHeater_Top_Cover_200W_r1.1.stl) | Top cover|
| [`Spacer.stp`](CAD/iHeater_Spacer_200W_r1.1.stl)| Spacer for power supply|
| [`iHeater_200W_r1.1.stp`](CAD/iHeater_200W_r1.1.stp)| Complete assembly in STEP format (for CAD systems) |
| [`iHeater_200W_r1.1_upd.stp`](CAD/iHeater_200W_r1.1_upd.stp) | Update. Complete assembly in STEP format (for CAD systems) |

### File Formats

* `.stl` - Used for 3D printing.
* `.stp` - Used for editing assemblies in CAD software (e.g., Fusion 360, FreeCAD).

### How to Use

1. Open [`iHeater.stp`](CAD/iHeater.stp) in your CAD software to view the full assembly.
2. Load the STL files into your slicer to prepare for 3D printing.
3. Make sure to set the import scale to **millimeters (mm)**.

### Enclosure Printing Material

Recommended materials:

* ABS, ABS-CF
* PA, PA-GF
* PP, PP-GF
* other materials capable of withstanding 90°C

### Notes

* Ensure that ventilation openings are not blocked during installation.
* STL files are optimized for support-free printing.

---

[*If you're editing CAD files - don’t forget to update this document too!*](https://github.com/pavluchenkor/iHeater/tree/main/User-mods)

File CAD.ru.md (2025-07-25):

## CAD файлы iHeater

В этой директории находятся 3D-модели компонентов корпуса и креплений устройства iHeater.

### Список файлов iHeater 100W

| Файл | Описание |
|---|---|
| [`Base.stl`](CAD/Base.stl) | Основание корпуса, на котором крепятся все компоненты |
| [`Cover Two Color.stl`](CAD/Cover%20Two%20Color.stl) | Верхняя крышка  печатается в два цвета|
| [`Cover.stl`](CAD/Cover.stl) | Верхняя крышка|
| [`iHeater.stp`](CAD/iHeater.stp) | Полная сборка в формате STEP (для CAD-систем) |

### Список файлов iHeater 200W

| Файл | Описание |
|---|---|
| [`iHeater_Base_200W.stl`](CAD/iHeater_Base_200W.stl) | Основание корпуса, на котором крепятся все компоненты |
| [`iHeater_Top_Cover_200_W_two_Color.stl`](CAD/iHeater_Top_Cover_200_W_two_Color.stl) | Верхняя крышка  печатается в два цвета|
| [`iHeater_Top_Cover_200W.stl`](CAD/iHeater_Top_Cover_200W.stl) | Верхняя крышка|
| [`iHeater.stp`](CAD/iHeater200W.stp) | Полная сборка в формате STEP (для CAD-систем) |
| [`iHeater_2.0.0.stp`](CAD/iHeater_2.0.0.stp) | Альтернативный вариант. Полная сборка в формате STEP (для CAD-систем) |

### Список файлов iHeater 200W r1.1 PCB

| Файл | Описание |
|---|---|
| [`iHeater_Base_200W_r1.1.stl`](CAD/iHeater_Base_200W_r1.1.stl) | Основание корпуса, на котором крепятся все компоненты |
| [`iHeater_Top_Cover_200W_r1.1_color.stl`](CAD/iHeater_Top_Cover_200W_r1.1_color.stl) | Верхняя крышка  печатается в два цвета|
| [`iHeater_Top_Cover_200W_r1.1.stl`](CAD/iHeater_Top_Cover_200W_r1.1.stl) | Верхняя крышка|
| [`Spacer.stp`](CAD/iHeater_Spacer_200W_r1.1.stl) | Проставка для блока питания |
| [`iHeater_200W_r1.1.stp`](CAD/iHeater_200W_r1.1.stp) | Полная сборка в формате STEP (для CAD-систем) |
| [`iHeater_200W_r1.1_upd.stp`](CAD/iHeater_200W_r1.1_upd.stp) | Обновление. Сборка в формате STEP (для CAD-систем) |

### Форматы файлов

- `.stl` - используется для 3D-печати.
- `.stp` - используется для редактирования сборки в CAD-программах (Fusion 360, FreeCAD и т.д.).

### Как использовать

1. Откройте [`iHeater.stp`](CAD/iHeater.stp) в вашей CAD-программе для обзора всей сборки.
2. Загрузите STL-файлы в ваш слайсер для подготовки к 3D-печати.
3. Убедитесь, что при импорте выбран масштаб **миллиметры (mm)**.

### Материал печати корпуса

Рекомендованные материалы:

* ABS, ABS-CF
* PA, PA-GF
* PP, PP-GF
* другие материалы выдерживающие 90С 

### Примечания

- Убедитесь, что вентиляционные отверстия не перекрыты при установке.
- STL-файлы оптимизированы для печати без поддержки.

---

[_Если вы редактируете CAD-файлы - не забудьте и про этот документ!_](https://github.com/pavluchenkor/iHeater/tree/main/User-mods)

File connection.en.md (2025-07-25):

## Wiring Diagram

The **iHeater** controller can operate both as part of a **Klipper** system (as an additional MCU) or autonomously using the integrated **standalone** firmware.

### Connecting for use with Klipper

For proper operation within Klipper, connect the following:

* **USB cable** to the main host (Host-MCU) — provides data communication and 5V power supply.
* **Power supply 220V / 110V** — depending on device version and heater type.
* **Heater thermistor** — to monitor heater temperature.
* **Chamber thermistor** — to monitor air temperature inside the printer chamber.
* **Trigger port** — optional, used for automatic control from an external signal.

During operation, the iHeater is located inside the 3D printer chamber.
!!! note annotate "It is recommended to place the chamber thermistor at the level of the toolhead, preferably **above the heated bed**."

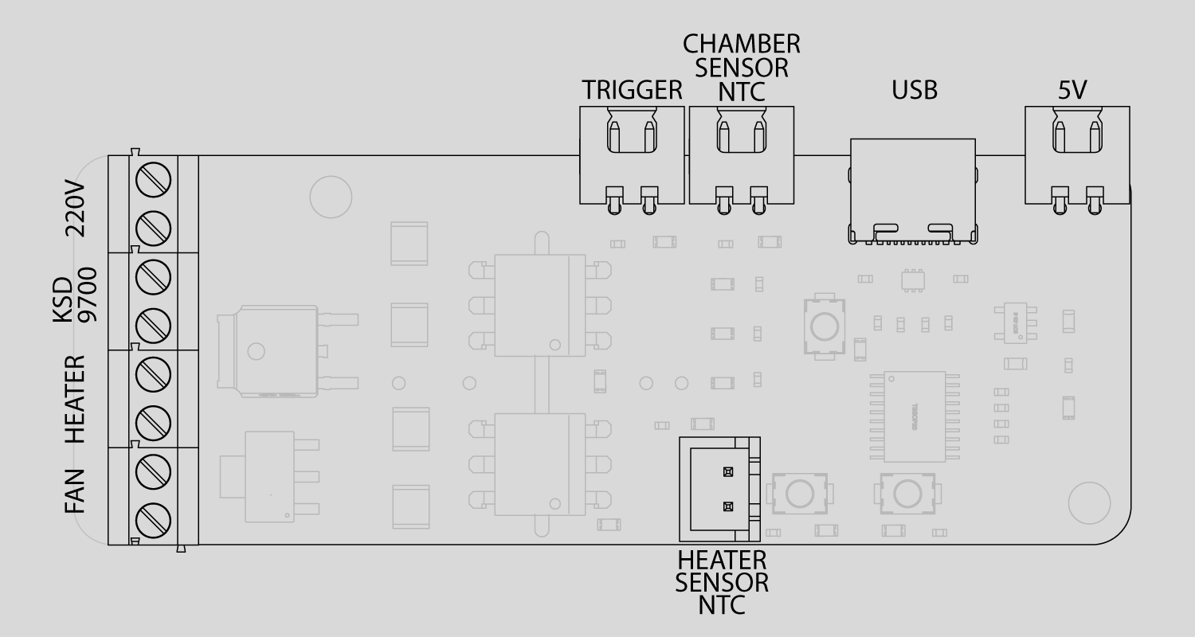
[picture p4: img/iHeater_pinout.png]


## GPIO Configuration

| Pin | Alias  | Function |
| --- | --- | --- |
| PA0 | TH1 | Chamber temperature sensor |
| PA1 | HEATER | Heater control |
| PA2 | FAN | Fan control |
| PA3 | TH0 | Heater temperature sensor  |
| PA4 | MODE | Mode button |
| PA5 | LED3 | LED 3 |
| PA6 | LED2 | LED 2 |
| PA7 | LED1 | LED 1 |
| PB1 | TH2 |Optional temperature sensor |

---

### Standalone mode usage

In standalone mode, additional functions and connection methods are available:

* **Trigger port in thermistor mode**
  By connecting a thermistor to the trigger port and placing it near the heated bed element, automatic control can be enabled:

  * Heater turns on when the bed heats above **45°C**.
  * Heater turns off when the temperature drops below **85°C**.

* **Power from an external 5V source**
  If USB power is unavailable, you can directly supply power through the corresponding connector.

* **Experimental option**
  Connect [5V power supply directly to the board](https://sl.aliexpress.ru/p?key=OHtN3Xm).

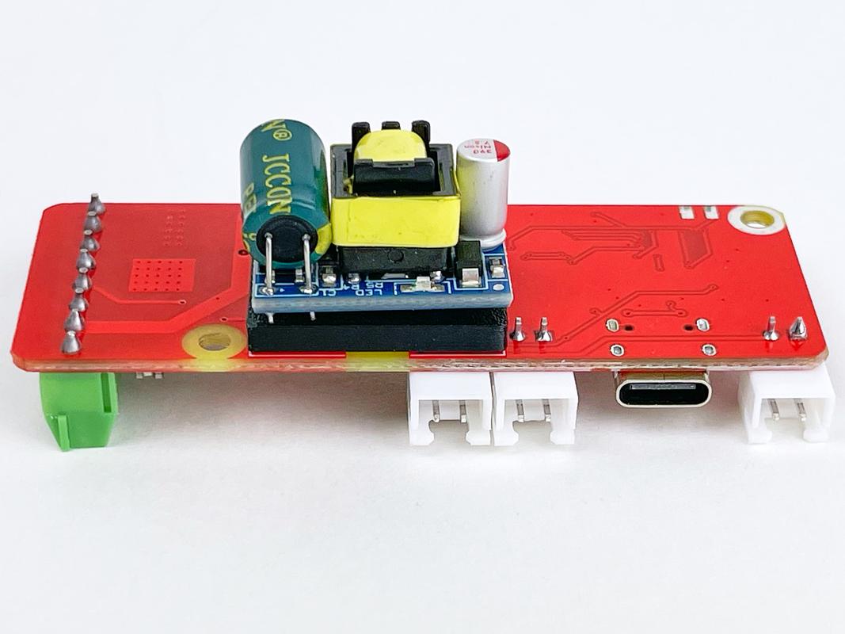
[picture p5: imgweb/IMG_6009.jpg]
Power Connection


---

### General Wiring Diagram

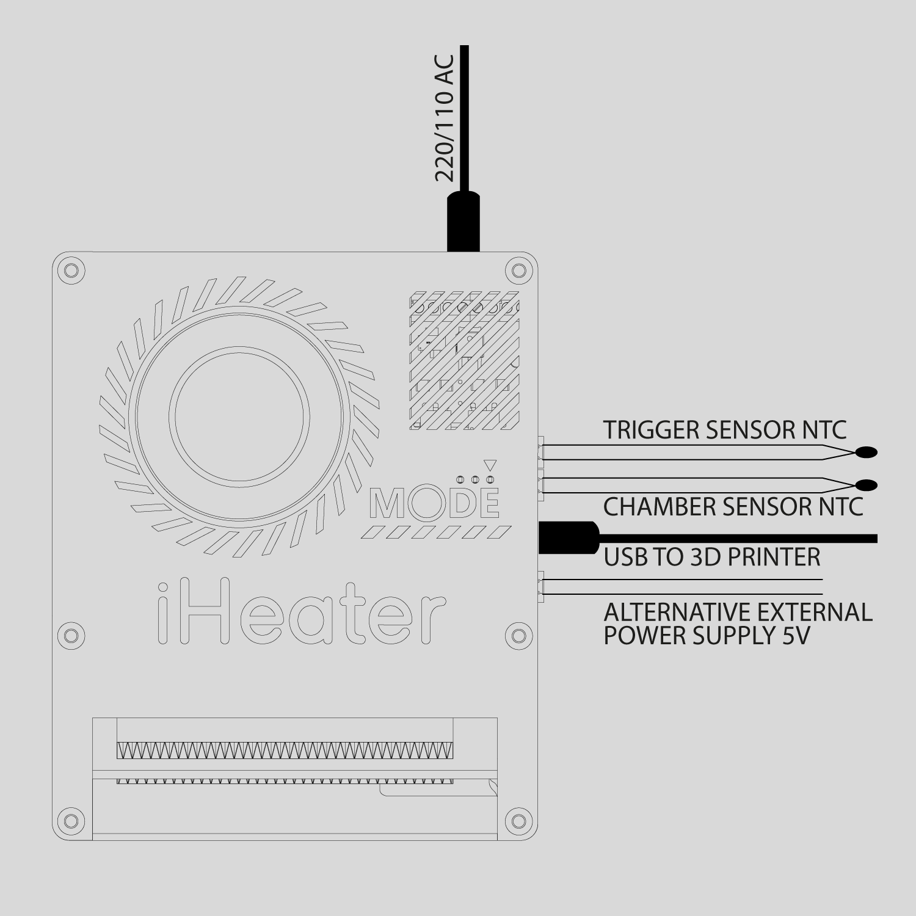
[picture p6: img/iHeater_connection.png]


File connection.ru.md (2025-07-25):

## Схема подключения

Контроллер **iHeater** может работать как в составе системы **Klipper** (в качестве дополнительного MCU), так и автономно — под управлением встроенной прошивки **standalone**.

### Подключение для работы с Klipper

Для корректной работы в составе Klipper необходимо подключить:

* **USB-кабель** к основному хосту (Host-MCU) - по нему осуществляется передача данных и питание 5В;
* **Силовое питание 220В / 110В** - в зависимости от версии устройства и типа нагревателя;
* **Термистор нагревателя** - для контроля температуры нагревательного элемента;
* **Термистор камеры** - для контроля температуры воздуха в камере принтера;
* **Порт триггера** - опциональное подключение, используется для автоматического управления от внешнего сигнала.

В рабочем состоянии iHeater размещается внутри камеры 3D-принтера.

!!! note annotate "Рекомендуется размещать термистор камеры на уровне печатающей головки, по возможности - **над столом**."

Схема подключения

## Конфигурация GPIO

| Pin | Alias | Function |
|---|---|---|
| PA0 | TH1 | Температурный датчик камеры |
| PA1 | HEATER | Управление нагревателем |
| PA2 | FAN | Управление вентилятором |
| PA3 | TH0 | Температурный датчик нагревателя  |
| PA4 | MODE | Кнопка режима |
| PA5 | LED3 | Светодиод 3 |
| PA6 | LED2 | Светодиод 2 |
| PA7 | LED1 | Светодиод 1 |
| PB1 | TH2 | Дополнительный температурный датчик|

---

### Использование в режиме standalone

В автономном режиме доступны дополнительные функции и способы подключения:

* **Порт триггера в режиме термистора**
  При подключении термистора к порту триггера и размещении его рядом с нагревательным элементам стола можно включить автоматическое управление:
  - при нагреве стола выше **45°C** - включается нагрев камеры;
  - при снижении температуры ниже **85°C** - нагрев отключается.

* **Питание от внешнего источника 5В**
  При невозможности использования USB-питания можно подать питание напрямую через соответствующий разъём.

* **Экспериментальная опция**
  Подключение [источника питания 5В напрямую на плату](https://sl.aliexpress.ru/p?key=OHtN3Xm).

Подключение питания

---

### Общая схема подключения

Схема подключения

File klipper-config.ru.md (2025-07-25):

<!-- ## Установка -->
### Конфигурация iHeater для Klipper

Данный раздел содержит конфигурационные файлы для нагревателя камеры 3D-принтера iHeater на основе прошивки Klipper и одноименной платы управления. Конфигурация предназначена для управления нагревом камеры и вентиляторами с помощью микроконтроллера iHeater.

### Требования

#### Аппаратное обеспечение
  - Плата управления iHeater
  - Терморезисторы NTC 100K 3950 (2 шт.)
  - PTC нагревательный элемент 220В 100Вт, для камеры
  - Вентилятор 7530 220В, для циркуляции воздуха в камере
  - Термофьюз KSD9700 или аналогичный (220В 5А 130С)

#### Программное обеспечение
  - Klipper (последняя версия)
  - Настроенный и работающий хост с Klipper

## Конфигурация Klipper

Скопируйте конфигурационные файлы iHeater.cfg в папку с файлом printer.cfg(это может быть /klipper_config) и подключите его в printer.cfg с помощью директивы [include]

```
cd ~/klipper_config
```

```
wget https://raw.githubusercontent.com/pavluchenkor/iHeater/refs/heads/main/iHeater.cfg
```

Откройте printer.cfg и добавьте

    [include iHeater.cfg]

## Подключение MCU iHeater

Измените файл iHeater.cfg, укажите полученный ID

```
    [mcu iHeater]
    serial: /dev/serial/by-id/usb-Klipper_stm32f042x6_ХХХХХХХХХХХХХХХХХХХХХХХ-ХХХХ

```

## Подготовка к использованию

Конфигурационный файл содержит секцию:

```ini
[gcode_macro CHAMBER_VARS]
variable_chamber_target: 0          # Целевая температура камеры, °C
variable_start_offset: 10           # Температура камеры, достаточная для начала печати, °C
variable_delta_temp: 10             # Разница между температурой камеры и нагревателя, °C
variable_min_heater_temp: 50        # Минимальная температура нагревателя (для охлаждения), °C
variable_max_heater_temp: 100       # Максимальная температура нагревателя, °C
variable_control_interval: 1.0      # Интервал вызова функции управления, секунды
variable_air_min_delta: 0.5         # Минимальная разница между целевой и текущей температурой камеры (нагреватель = целевая + delta_temp), °C
variable_air_max_delta: 5.0         # Максимальная разница между целевой и текущей температурой камеры (нагреватель = max_heater_temp), °C
gcode:
```

**Максимально допустимая температура нагревателя зависит от материала корпуса.**

Для проверки:

!. Включите нагрев стола 90-100°C
1. Установите температуру нагревателя на 100°C через интерфейс Fluidd или Mainsail.
2. Убедитесь, что iHeater находится внутри закрытого объема принтера.
3. После достижения установленной температуры проверьте участки, где нагреватель соприкасается с пластиковыми элементами корпуса. Пластик не должен размягчаться.
4. Увеличьте температуру на 5-10°C и повторите проверку.
5. Повторяйте, пока не будет достигнута максимально допустимая температура нагревателя без риска деформации корпуса.

Такой подход позволяет определить безопасный температурный максимум и достичь наилучшей эффективности работы iHeater.

## Использование

### Команды управления нагревом камеры
- Установка температуры камеры:

        M141 S60  ; Устанавливает температуру камеры на 60°C

- Ожидание достижения температуры:

        M191 S60  ; Ждет, пока температура камеры достигнет 60°C

- Остановка нагрева камеры:

        iHEATER_OFF   ; Отключает нагрев камеры

- В завершении G-кода слайсера добавьте `iHEATER_OFF`, чтобы корректно отключить нагрев камеры.

### Стартовый g-code

Современные слайсеры поддерживают автоматическое включение активной термокамеры при формировании g-code печати. Для этого, в свойствах филамента необходимо указать температуру камеры. В случае если слайсер не обладает этим функционалом, в стартовый g-code необходимо добавить команду включения нагрева активной термокамеры.

Порядок действий:

- Установить целевую температуру камеры
- Включить нагрев стола для эффективного и быстрого нагрева камеры 
- Продолжить стандартный стартовый G-code печати

Пример стартового g-code
```
; --- Начало стартового G-code ---

; ****** Старт iHeater ******
M141 S60       ; Установить температуру камеры на 60°C
; ****** Конец блока iHeater ******

; --- Остальной стартовый g-code ---
; Включение нагрева стола
...
```
!!! warning "Для корректного завершения работы макроса управления iHeater необходимо добавить в завершающий g-code принтера команду iHEATER_OFF"

```
; --- Начало завершающего g-code ---

; ****** Старт блока iHeater ******
iHEATER_OFF
; ****** Конец блока iHeater ******

; --- Остальной завершающий g-code ---
...
```
## Отключение

Для отключения iHeater в файле printer.cfg нужно закомментировать строку [include iHeater.cfg]
```
# [include iHeater.cfg]
```

И удалить из стартового и завершающего g-code соответствующе строки

## Примечания
- Безопасность:

    - Убедитесь, что все подключения выполнены правильно и безопасно.
    - Проверьте, что значения min_temp и max_temp соответствуют спецификациям оборудования.

- Проверка оборудования:
    - Перед использованием протестируйте работу нагревателя и вентилятора.
    - Следите за температурой во время первых запусков.
- Настройка PID:
    - При необходимости выполните калибровку PID для точного контроля температуры.

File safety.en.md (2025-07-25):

## Safety
The iHeater controller can operate both as part of the Klipper firmware and autonomously under its own built-in firmware (standalone). In both modes, advanced protection algorithms are implemented, with the standalone mode utilizing the same protections as in Klipper:

- Temperature control using thermistors;
- Checking for the presence of sensor connections;
- Protection against temperature exceeding safe limits;
- Use of timers in case the system hangs;
- Automatic shutdown in case of sensor or controller errors.

Additionally, hardware protection is implemented:

A KSD9700 thermal switch (135°C) is installed to provide physical disconnection of the heater power in case of overheating. Once the temperature drops below the threshold, the device automatically restores the connection, re-enabling power to the heater.

This type of protection is especially important in the event of software errors or hardware malfunctions, as it operates independently of the controller logic.

!!! note warning "Using a Thermal Fuse"
    In situations where the iHeater is used without continuous operator supervision, it is recommended to replace the KSD9700 thermal switch with a thermal fuse, providing hardware protection against overheating.

    One suitable option is the RH130 model, which has similar dimensions and can be installed in the standard iHeater housing position or mounted directly on the heatsink.

    Upon reaching the critical temperature, the fuse irreversibly opens the circuit, completely de-energizing the system and preventing overheating. Note that such devices are single-use and require replacement after activation.

The controller is equipped with a 2A fuse, which protects the device, and in case of an emergency, it blows, completely cutting off the system's power.

A PTC heating element with full electrical insulation is used. Unlike most heating solutions, the PTC heater's casing is not energized, eliminating the risk of electric shock during installation or maintenance of the 3D printer chamber.

This multi-layered protection system makes the iHeater a safe solution for active heating of 3D printer chambers, including during long continuous operation.

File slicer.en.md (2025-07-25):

## Configuring Start G-code in the Slicer for Proper iHeater Operation

To ensure even heating and stable printing with technical materials, it is important to correctly arrange the command sequence in the start G-code. Below are recommendations for integrating the iHeater chamber heating into the start code of your slicer (e.g., Cura, PrusaSlicer, OrcaSlicer, etc.).

### What Needs to Be Done

Before activating the chamber heating, you should:

**Enable bed heating**

   Preheating the bed helps the chamber to heat more evenly and quickly. The bed acts as an additional heat source, promoting more efficient chamber heating.

   ```
   M140 S[first_layer_bed_temperature]
   ```

**Activate the air circulation fan (if used)**

   This could be a side fan or any other fan intended to distribute heat evenly within the chamber.
   If it is named `chamber_fan` in your Klipper configuration:

   ```
   SET_FAN_SPEED FAN=chamber_fan SPEED=1.0
   ```
Some printers are equipped with exhaust fans that maintain the minimum possible temperature in the chamber. This is important when printing with materials such as PLA and PETG, but it hinders the speed of chamber heating. Such a fan can be assigned a new temperature parameter, for example, chamber_target_temperature + 10.

```
SET_TEMPERATURE_FAN_TARGET TEMPERATURE_FAN=chamber_fan TARGET={chamber_temperature + 10}
```

**Start chamber heating using one of the macros: `M141` or `M191`**

### Difference Between `M141` and `M191`

| Macro  | Purpose | Does It Block Code Execution? |
| --- | --- | --- |
| `M141` | Sets the target chamber temperature | No (heating begins, but printing continues immediately) |
| `M191` | Sets the chamber temperature and waits until it reaches the set value | Yes (next command runs only after chamber reaches set temp) |

#### Examples:

* If you want to start chamber heating immediately and perform all initial operations in parallel with the heating, then continue printing without waiting for the chamber to fully heat up, use the following. This works well for plastics like ABS and large models - the chamber will have time to heat up during the first few layers:

  ```
  M141 S60
  ```

* If you are printing a small part or require a stable chamber temperature (e.g., when printing PA, PC, and other sensitive materials), it's better to use the command that waits for the chamber to heat up:

  ```
  M191 S60
  ```

### After Chamber Heating

After calling one of the macros (`M141` or `M191`), you can proceed with the usual start G-code:

```gcode
M190 S[first_layer_bed_temperature]  Wait for bed to heat
M109 S[first_layer_temperature]  Wait for hotend to heat
G28  Homing
G29  (if auto-leveling is used)
...
```

### Recommendations

* If using `M191`, you can define a small offset at which the chamber is considered sufficiently heated (e.g., 5°C below target) - this is set in the [gcode_macro CHAMBER_VARS] macro `variable_start_offset`.
* Make sure that all macros used (`M141`, `M191`) are included and correctly configured in your Klipper setup.
* If your slicer supports conditions, you can add a check - for example, only activate the chamber if the print temperature exceeds 50°C (for ABS, ASA, etc.).

---

### Setting Chamber Temperature in the Slicer

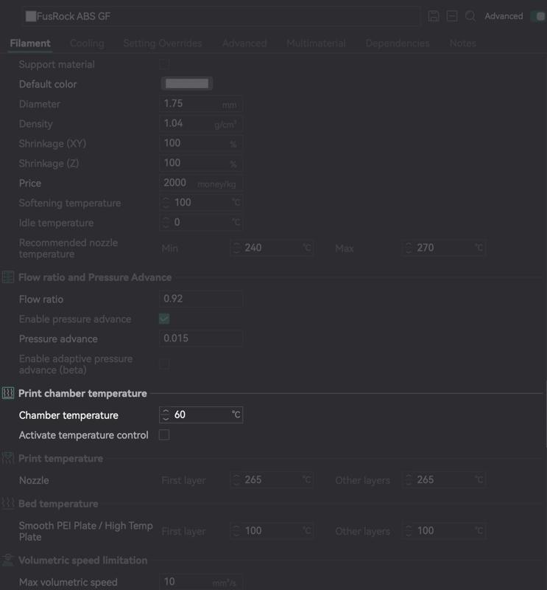
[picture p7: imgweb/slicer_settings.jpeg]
Slicer_settings


Many modern slicers allow you to specify the desired chamber temperature directly in the filament profile. This value is convenient to use as the `S` parameter for the `M141` or `M191` macros.

The screenshot shows the "Chamber temperature" field with a value of 60°C. This is just a numerical value - not all slicers actually send a command to heat the chamber. To ensure the temperature is applied, you need to check the G-code generated by the slicer and include commands in the start G-code if necessary:

```gcode
M141 S{chamber_temperature}
```

or

```gcode
M191 S{chamber_temperature}
```

Also, make sure the variable `chamber_temperature` is defined in the slicer's settings, or replace it with a number manually.

If the "Activate temperature control" option is enabled, some slicers automatically add an `M191` command with the specified temperature. This is convenient if you want the chamber to heat up with a wait before printing.

Manual control via macros is recommended to maintain full control over the heating logic and sequence of operations.

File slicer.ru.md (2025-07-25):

## Настройка стартового G-code в слайсере для корректной работы iHeater

Для достижения равномерного прогрева и стабильной печати с техническими материалами важно правильно настроить порядок команд в стартовом G-code. Ниже приведены рекомендации по интеграции нагрева камеры iHeater в стартовый код вашего слайсера (например, Cura, PrusaSlicer, OrcaSlicer и т.д.).

### Что нужно сделать

Перед включением нагрева камеры необходимо:

**Включить нагрев стола**

   Прогрев стола помогает камере прогреваться равномернее и быстрее Такой стол выступает как дополнительный источник тепла, который способствует более эффективному прогреву всей камеры.

   ```
   M140 S[first_layer_bed_temperature]
   ```

**Включить вентилятор перемешивания воздуха (если используется)**

   Это может быть боковой вентилятор или любой другой, предназначенный для равномерного распределения тепла в камере.
   Если в конфигурации Klipper он называется, например, `chamber_fan`, то:

   ```
   SET_FAN_SPEED FAN=chamber_fan SPEED=1.0
   ```

В некоторых принтерах установлены вытяжные вентиляторы поддерживающие минимально возможную температур в камере, это важно при печати такими пластиками как PLA и PETG, но вредит скорости нагрева камеры. Такому вентилятору можно передать новый параметр температуры, например целевая_температура_в_камере + 10

```
SET_TEMPERATURE_FAN_TARGET TEMPERATURE_FAN=chamber_fan TARGET={chamber_temperature + 10}
```

**Включить нагрев камеры с помощью одного из макросов: `M141` или `M191`**

### Разница между `M141` и `M191`

| Макрос | Назначение | Блокирует ли выполнение кода |
| --- | --- | --- |
| `M141` | Устанавливает целевую температуру камеры | Нет (нагрев начинается, но печать продолжается сразу) |
| `M191` | Устанавливает температуру камеры и ждет, пока она достигнет заданного значения | Да (переход к следующей команде произойдёт только после прогрева) |

#### Примеры:

* Если вы хотите немедленно начать прогрев камеры и выполнять все предварительные операции параллельно нагреву, а затем продолжить печать, не дожидаясь полного прогрева камеры, подойдет такой вариант. Это хорошо работает для пластиков типа ABS и крупных моделей - пока печатаются первые несколько слоев, камера успеет прогреться:

  ```
  M141 S60
  ```

* Если печатается маленькая деталь или требуется стабильная температура камеры (например, при печати PA, PC и других чувствительных материалов), лучше использовать команду с ожиданием прогрева:

  ```
  M191 S60
  ```

### После нагрева камеры

После вызова одного из макросов (`M141` или `M191`) можно продолжать обычный стартовый G-code:

```gcode
M190 S[first_layer_bed_temperature]  Ожидание нагрева стола
M109 S[first_layer_temperature]  Ожидание нагрева хотэнда
G28  Хоуминг
G29  (если используется автокалибровка)
... 
```

### Рекомендации

* Если вы используете `M191`, можно задать небольшое отклонение, при котором камера считается достаточно прогретой (например, 5°C ниже цели) - это настраивается в макросе [gcode_macro CHAMBER_VARS] `variable_start_offset`.
* Убедитесь, что все используемые макросы (`M141`, `M191`) подключены в конфигурации Klipper и настроены корректно.
* Если ваш слайсер поддерживает условия, можно добавить проверку: например, включать камеру только при температуре печати выше 50°C (для ABS, ASA и т.д.).

---

### Настройка температуры в термокамере в слайсере

Slicer_settings

Во многих современных слайсерах можно указать желаемую температуру термокамеры прямо в профиле филамента. Это значение удобно использовать как параметр `S` для макросов `M141` или `M191`.

На скриншоте показано поле "Chamber temperature", в котором задано значение `60°C`. Это лишь числовое значение - **не все слайсеры не отправляет команду на нагрев камеры**. Чтобы температура действительно применялась, необходимо проверить формирование G-code слайсером использовать команды в стартовом G-code в случае необходимости:

```gcode
M141 S{chamber_temperature}
```

или

```gcode
M191 S{chamber_temperature}
```

Также убедитесь, что переменная `chamber_temperature` задана в настройках слайсера, или замените её числом вручную.

Если активировать опцию "Activate temperature control", некоторые слайсеры автоматически добавляют команду `M191` с заданным значением температуры. Это удобно, если вы хотите, чтобы прогрев камеры происходил с ожиданием перед печатью.

Рекомендуется использовать ручное управление через макросы, чтобы иметь полный контроль над логикой прогрева и последовательностью действий.

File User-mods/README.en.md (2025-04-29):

# How to Add Your Mod to This Repository

This guide is for users who want to add their own mods to this repository. Please follow the instructions below step by step to ensure your mod is correctly structured and easy to understand for others.

**Important: Original files are provided under the CC BY-NC-SA license. Any modifications or derivatives must be shared in this repository in accordance with the license terms and the repository submission guidelines. Commercial use is strictly prohibited.**

---
## 1. Fork the Repository (Required)
Before making changes, you must fork this repository to your own GitHub account:

Open the repository in GitHub:
https://github.com/pavluchenkor/iHeater
Click the "Fork" button in the top-right corner.
Choose your GitHub account as the destination.
Wait for GitHub to create a fork (this is your personal copy of the repository).

## 2. Clone Your Fork
After forking the repository, clone your own fork, not the original repository:

Option 1: Using Git (Recommended)
```
git clone https://github.com/YOUR-USERNAME/iHeater.git
cd iHeater
```
(Replace YOUR-USERNAME with your GitHub username.)

### Option 1: Using Git (Recommended)

1. Open your terminal or command prompt.
2. Clone the repository by running the following command:
   ```bash
   git clone https://github.com/pavluchenkor/iHeater.git

### Option 2: Download as a ZIP File

1. Click the green "Code" button at the top of the repository page.
2. Select "Download ZIP".
3. Extract the ZIP file to your computer.

## 3. Add Your Mod to the Correct Folder

Based on the type of mod you're creating, it should go into one of the following main directories:

#### Software Mods:

- If your mod involves configuration files, scripts, or code, it should be added to the software/ folder.

#### Hardware Mods:

- If your mod involves CAD models, mechanical components, or hardware designs, it should be added to the hardware/ folder.

### Examples:

#### For a Software Mod:
If your mod is called "CoolMod" and involves configuration or scripts, your folder structure should look like this:

```
├── hardware/
├── software/
│   ├── CoolMod/
│   │   ├── README.md
│   │   ├── scripts/
│   │   ├── config/
├── readme.md

```

#### For a Hardware Mod:
If your mod is called "CoolMod" and involves CAD models or mechanical components, your folder structure should look like this:
```
├── hardware/
│   ├── CoolMod/
│   │   ├── README.md
│   │   ├── models/
│   │   ├── assembly/
│   │   ├── diagrams/
├── software/
├── readme.md

```
## 4. Organize Your Mod Files

In your mod folder, create a clear and logical structure for your files. At a minimum, your mod folder should include the following:

### For Software Mods:

- README.md: A markdown file describing your mod (see template below).
- scripts/: A folder for scripts or additional functionality.
- config/: A folder for configuration files (if applicable).

### For Hardware Mods:

- README.md: A markdown file describing your mod (see template below).
- models/: A folder for CAD models or 3D files (e.g., .stl, .step).
- assembly/: A folder for assembly instructions or exploded views.
- diagrams/: A folder for electrical or mechanical diagrams.

## 5. Write a README.md for Your Mod

Every mod must include a README.md file inside its folder. This file should provide clear and detailed information about your mod. Use the following template to guide you:

### Template for README.md

#### [Mod Name]

##### Summary
A brief overview of your mod. Explain its purpose and what problem it solves.

#### Example:
"CoolMod is a software configuration mod for enhancing filament drying with custom profiles."

---

#### Features
- List the key features of your mod.
- Example:
- Supports multiple drying profiles.
- Offers advanced temperature and humidity control.

---

#### How to Use
Step-by-step instructions on how to use your mod. Include:
1. Installation instructions.
2. Integration steps (e.g., how to include it in the main repository).
3. Dependencies or requirements.

#### Example:
1. Copy the `CoolMod` folder into the `klipper/` directory.
2. Include the configuration in Klipper by adding:

   ```ini
   [include CoolMod/config/coolmod.cfg]
   ```

### Full Description

Provide detailed information about your mod, including:

- Screenshots or diagrams.
- Code snippets or configuration examples.
- Supported hardware/software versions.
- Specific use cases.

### Example:
Screenshots:
Code Snippet:

```
[gcode_macro COOL_MOD_START]
gcode:
    M117 Starting CoolMod...
```

### Notes
- Known limitations or compatibility issues.
- Suggestions for future updates or improvements.

### Author

Add your name or GitHub handle here (optional).

## 6. Submit Your Mod

### Option 1: Using Git

1. Add your changes to the repository:

```bash
git add .
git commit -m "Added CoolMod"
git push
```

2. Create a pull request on GitHub to merge your changes into the main repository.

### Option 2: Upload Files on GitHub

1. Open the repository on GitHub.
2. Navigate to the folder where you want to add your mod (hardware/ or software/).
3. Click "Add file" > "Upload files".
4. Select your mod folder and upload it.
5. Create a pull request to merge your changes.

## Important Notes

- Do not modify existing files or folders in the repository.
- Ensure your folder structure is clear and logical.
- Test your mod thoroughly before submitting it.
- Write a comprehensive and user-friendly README.md.

By following these guidelines, your mod will be easy to integrate and understand. If you have any questions, feel free to contact.

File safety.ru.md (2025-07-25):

## Безопасность
Контроллер iHeater может работать как в составе прошивки Klipper, так и автономно - под управлением собственной встроенной прошивки (standalone). В обоих режимах реализованы продвинутые алгоритмы защиты, в standalone режиме аналогичные тем, что используются в Klipper:

- контроль температуры с помощью термисторов;
- проверка наличия подключения термодатчиков;
- защита от выхода температуры за пределы безопасных значений;
- использование таймеров на случай зависания системы;
- автоматическое отключение при ошибках датчиков или контроллера.

Дополнительно реализована аппаратная защита:

Установлен термопредохранитель KSD9700 (135°C), который в случае перегрева физически отключает питание нагревательного элемента. При снижении температуры ниже порогового значения устройство автоматически замыкает цепь, восстанавливая питание.

Такая защита особенно важна при любых программных сбоях или аппаратных неисправностях, поскольку работает независимо от логики управления контроллера.

!!! warning "Установка термистора"
    Убедитесь, что провода термистора не соприкасаются с металлическим корпусом нагревателя. Если есть сомнения, термистор следует заизолировать - например, обмотать каптоновым скотчем или поместить в любой термостойкий изолирующий материал (например, тефлоновую трубку или термоусадочную изоляцию).

    Помните, температура нагревателя может достигать 140С

!!! warning "Установка термопредохранителя"
    Вы можете установить либо самовосстанавливающийся термовыключатель, такой как KSD9700, либо плавкий термопредохранитель.

    Имейте в виду, что плавкий предохранитель — это одноразовое защитное устройство: при превышении температуры он навсегда разрывает цепь, и для восстановления потребуется его замена на аналогичный.

    В свою очередь, KSD9700 представляет собой биметаллический термовыключатель. Он размыкает цепь при достижении заданной температуры и автоматически замыкает её обратно, когда температура опускается ниже установленного порога. Это позволяет системе восстановить работу без замены компонента.

    С точки зрения безопасности, плавкий предохранитель обеспечивает более надёжную защиту, поскольку исключает повторное включение в случае неисправности или перегрева.

    Поскольку это DIY-проект, и работа с нагревательными элементами требует понимания принципов электрической безопасности, если вы не уверены в своих действиях, рекомендуется сначала настроить систему с использованием KSD9700 (для тестирования и отладки), а затем заменить его на соответствующий плавкий предохранитель(например RH130).

Контроллер оборудован предохранителем на 2 А, который защищает устройство, в аварийной ситуации он перегорает, полностью обесточивая систему.

Применяется PTC-нагревательный элемент с полной электрической изоляцией. В отличие от большинства нагревательных решений, корпус PTC-нагревателя не находится под напряжением, что исключает риск поражения электрическим током при установке и при обслуживании камеры 3D-принтера.

Такая многоуровневая система защиты делает iHeater безопасным решением для активного нагрева камер 3D-принтеров, в том числе при длительной непрерывной работе.

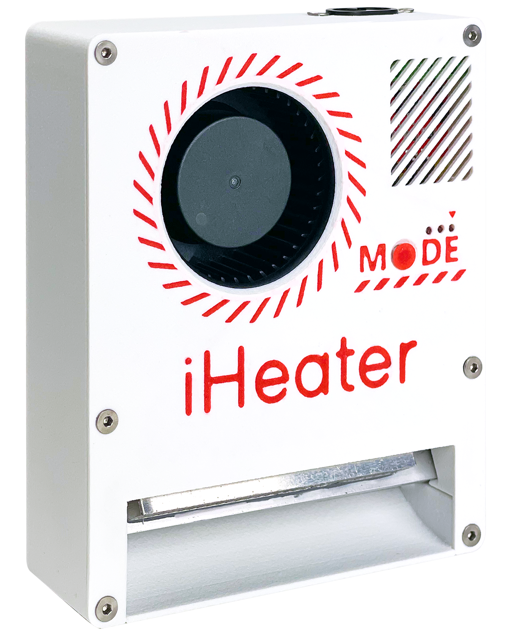
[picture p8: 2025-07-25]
img/iHeater_200.png

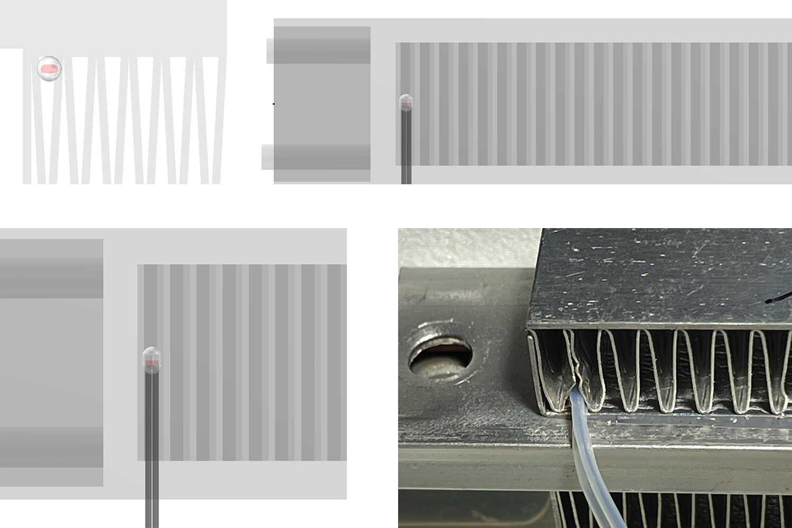
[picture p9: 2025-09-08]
img/thermistor.jpg

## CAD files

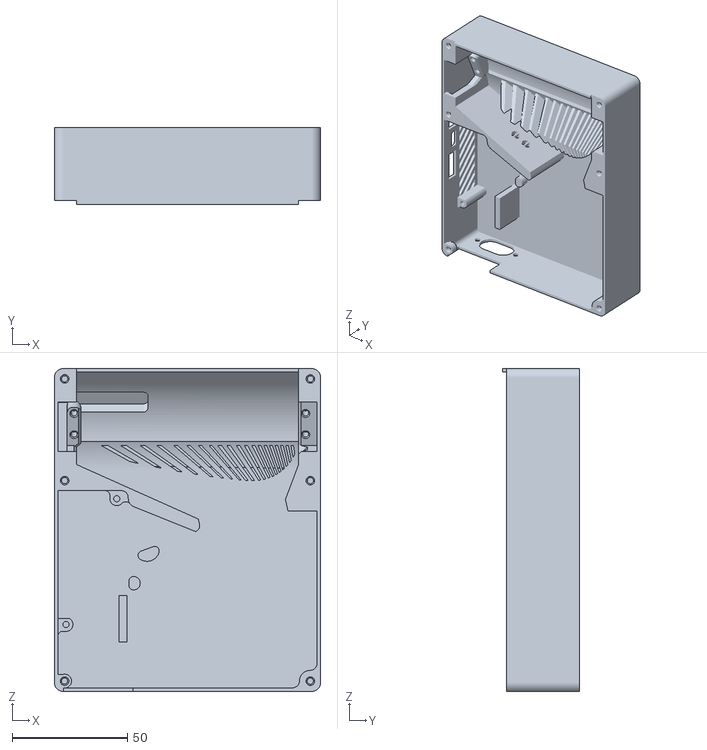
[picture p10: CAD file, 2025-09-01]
CAD/iHeater_Base_200W_r1.1.stl
115.5 x 33.2 x 140.0

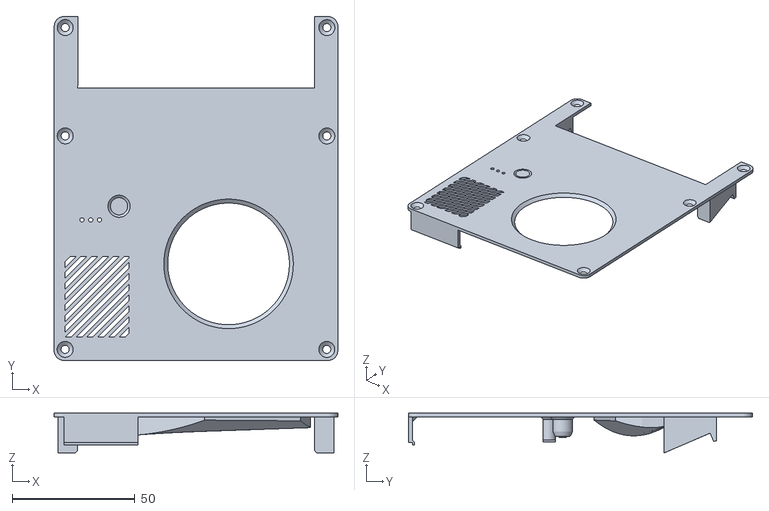
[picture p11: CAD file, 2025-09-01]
CAD/iHeater_Top_Cover_200W_r1.1_color.stl
115.5 x 140.0 x 16.2

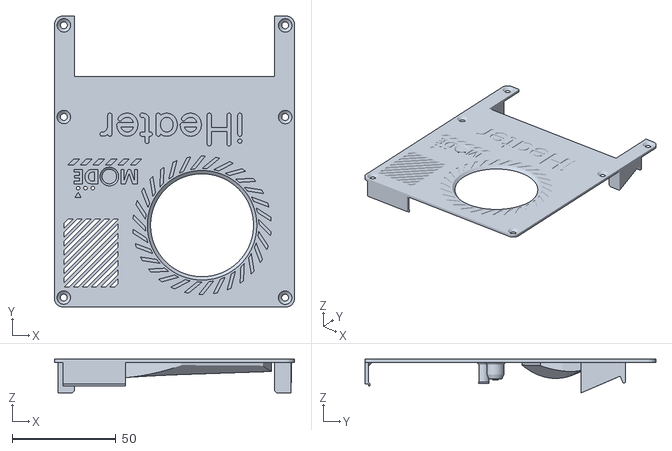
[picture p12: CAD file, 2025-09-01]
CAD/iHeater_Top_Cover_200W_r1.1.stl
115.5 x 140.0 x 16.2

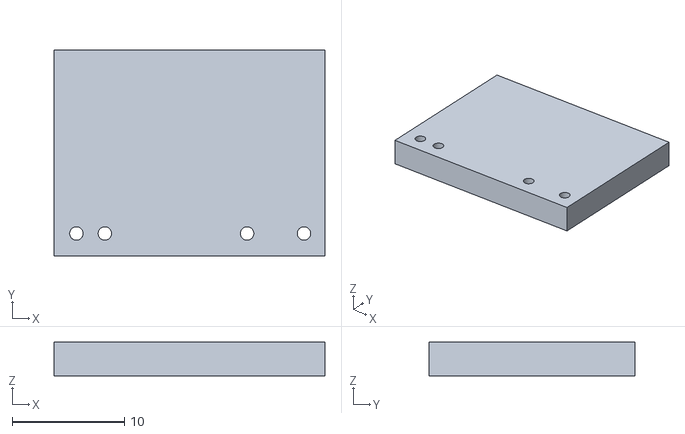
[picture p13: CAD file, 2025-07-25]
CAD/iHeater_Spacer_200W_r1.1.stl
24.2 x 18.4 x 3.00

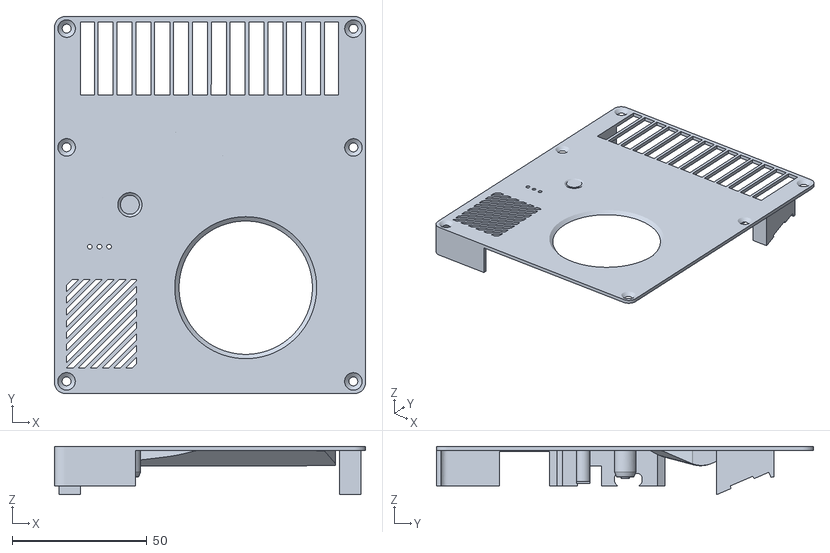
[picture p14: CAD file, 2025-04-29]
CAD/iHeater_Top_Cover_200_W_two_Color.stl
115.5 x 140.0 x 18.0

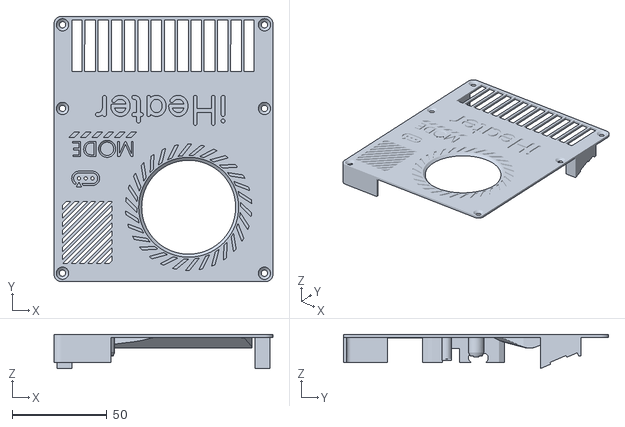
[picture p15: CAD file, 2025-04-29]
CAD/iHeater_Top_Cover_200W.stl
115.5 x 140.0 x 18.0

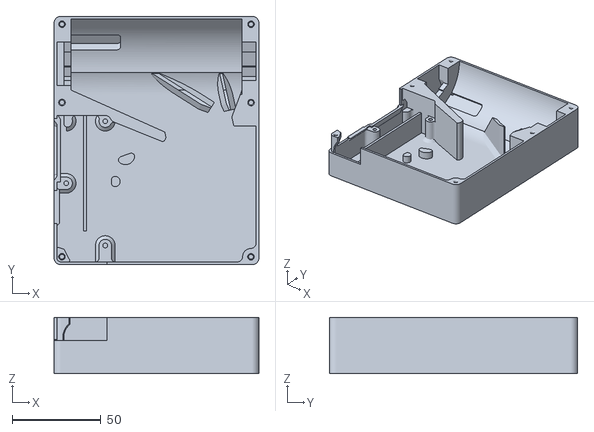
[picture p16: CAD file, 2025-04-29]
CAD/iHeater_Base_200W.stl
115.5 x 140.0 x 31.6

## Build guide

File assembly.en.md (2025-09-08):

## Assembly

# Before Assembly

## Documentation

Review the documentation, download and print the necessary parts. Ensure that all required parts and tools are available.

## Getting Started with Assembly

It is recommended to first assemble the entire system **on the table**, without mounting it into the enclosure, and perform testing:

* Connect **all** components.
* Verify the functionality of the heater, fan, and temperature sensors.
* Connect the system to **Klipper** or flash standalone firmware and ensure proper operation of the macros.

Video guide: [YouTube](https://youtu.be/1QMtVY0Vx-8?si=Ol1u4Ux9wALDcfe2)

### Installing the Board

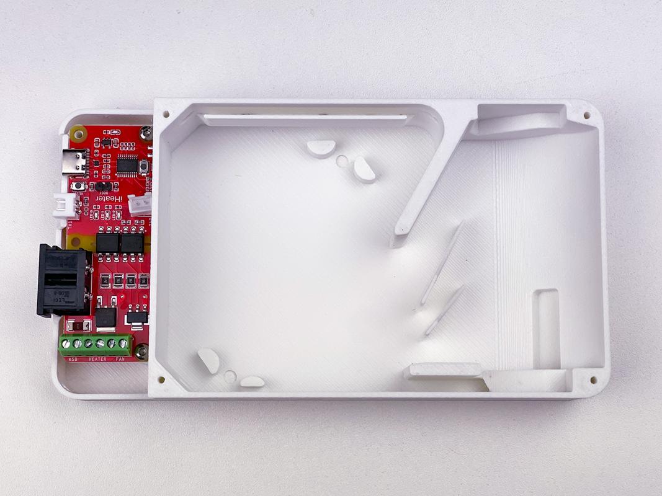
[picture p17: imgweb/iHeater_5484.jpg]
iHeater Assembly


### Installing the Thermistor and thermal fuse

!!! warning "Installing the thermistor"
    Make sure that the thermistor wires do not come into contact with the metal body of the heater. If you're unsure, insulate the thermistor - for example, by wrapping it with Kapton tape or placing it in any heat-resistant insulating material, such as a Teflon sleeve or heat-shrink tubing.
    
    Keep in mind that the heater temperature can reach up to 140°C.

!!! warning "Thermal Fuse Installation"
    You can install either a resettable thermal switch (such as the KSD9700) or a thermal fuse.

    Keep in mind that a thermal fuse is a one-time protection device: when the rated temperature is exceeded, it permanently breaks the circuit and must be replaced with an identical fuse.

    In contrast, the KSD9700 is a bimetallic thermal switch. It cuts off power when a set temperature is reached and automatically reconnects the circuit once the temperature drops below the threshold. This allows the system to recover without needing to replace the component.

    From a safety perspective, a thermal fuse offers more reliable protection, as it completely shuts down the system in case of overheating and prevents it from turning back on automatically.

    Since this is a DIY project, and working with heating elements requires a clear understanding of electrical safety, it’s recommended to first test your setup using a KSD9700, and once everything is working correctly, replace it with an appropriate thermal fuse(one suitable option is the RH130 model) for maximum safety.

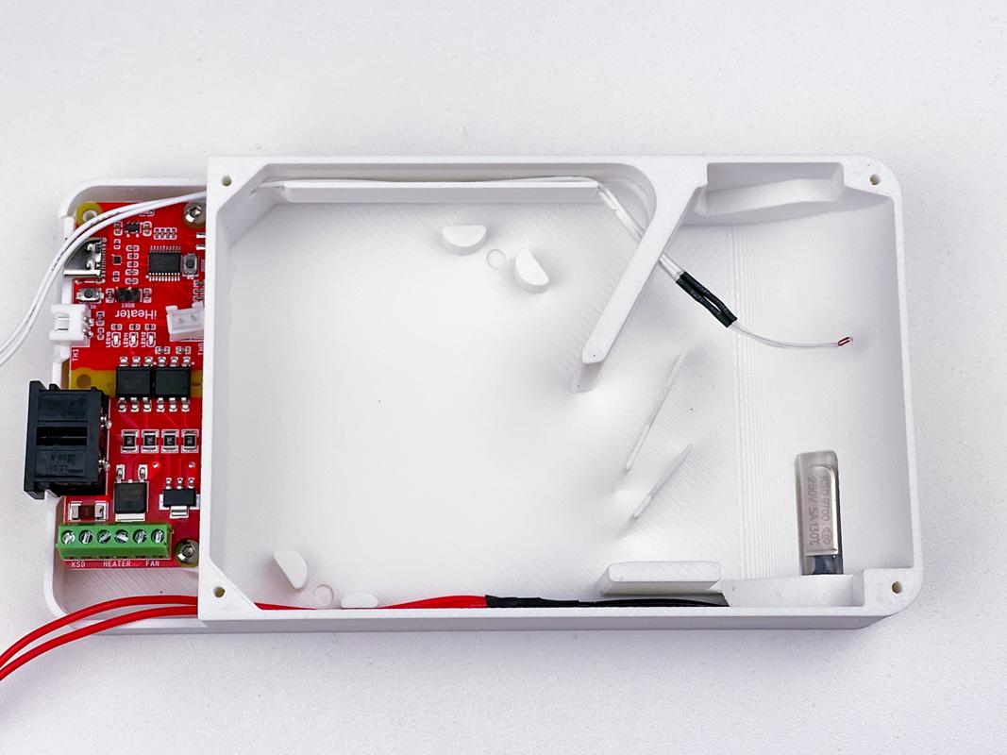
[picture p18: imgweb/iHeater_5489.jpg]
iHeater Assembly

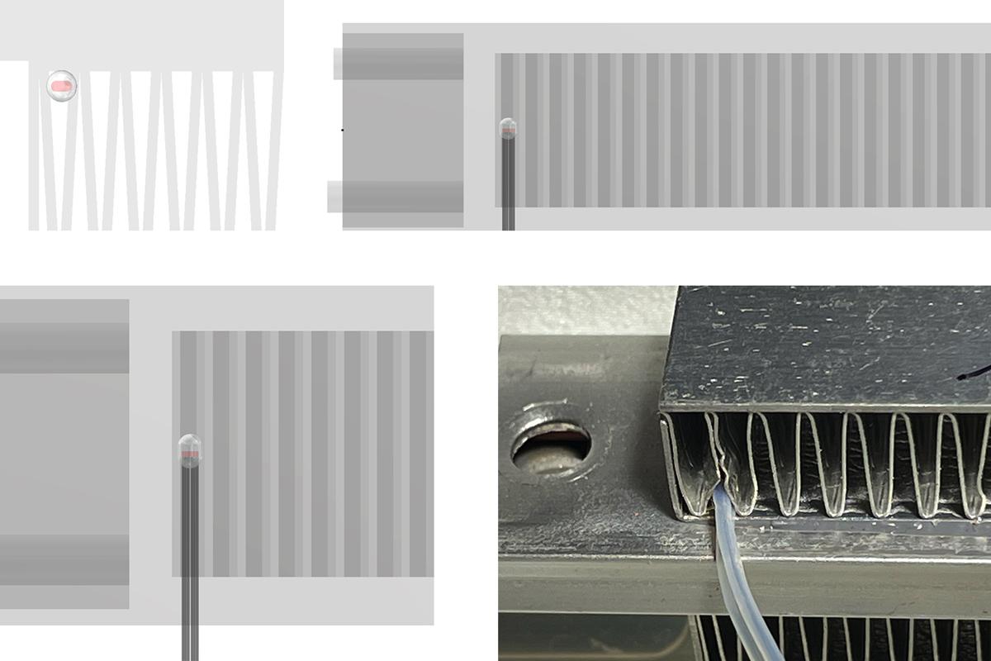
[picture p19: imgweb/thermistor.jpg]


### Installing the Heater

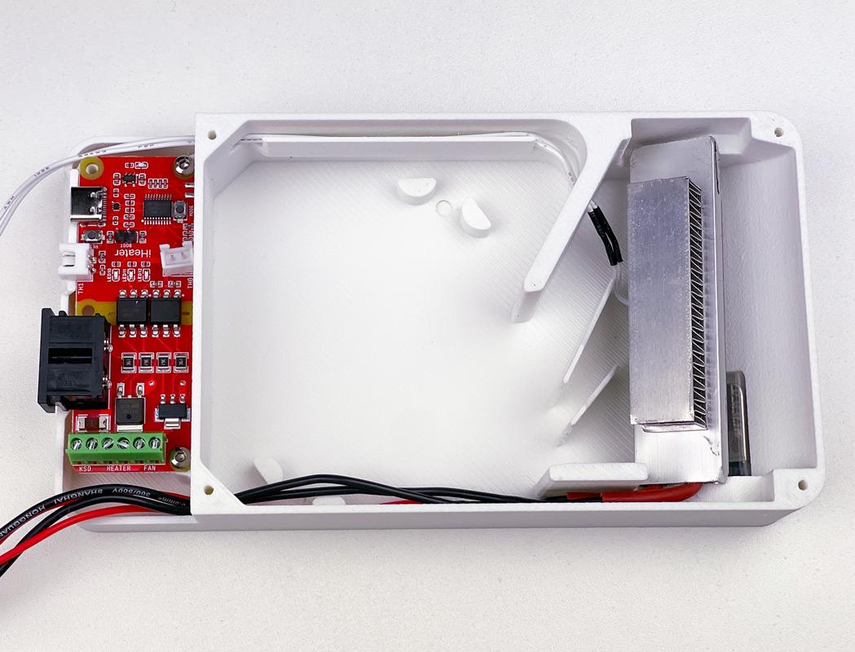
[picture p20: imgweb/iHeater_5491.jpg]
iHeater Assembly


### Wiring

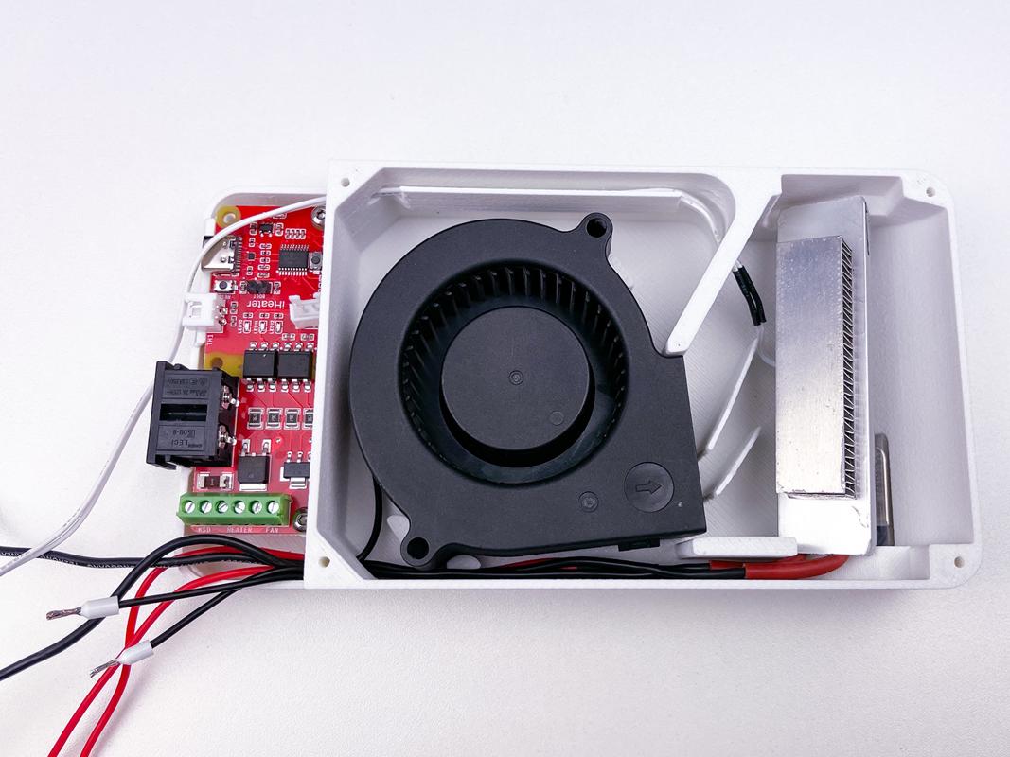
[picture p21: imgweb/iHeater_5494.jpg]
iHeater Assembly


### Installing

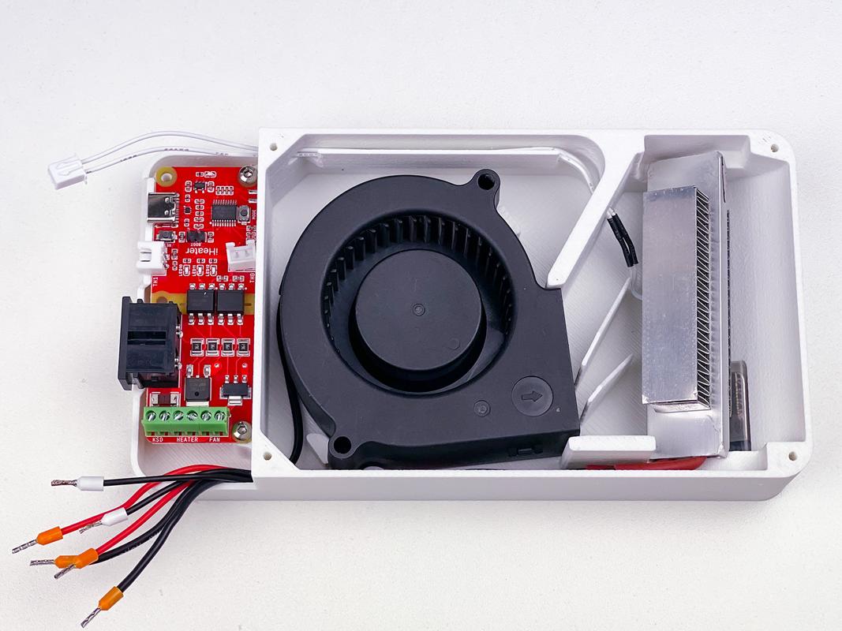
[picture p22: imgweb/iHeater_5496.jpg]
iHeater Assembly


### Wiring Connections

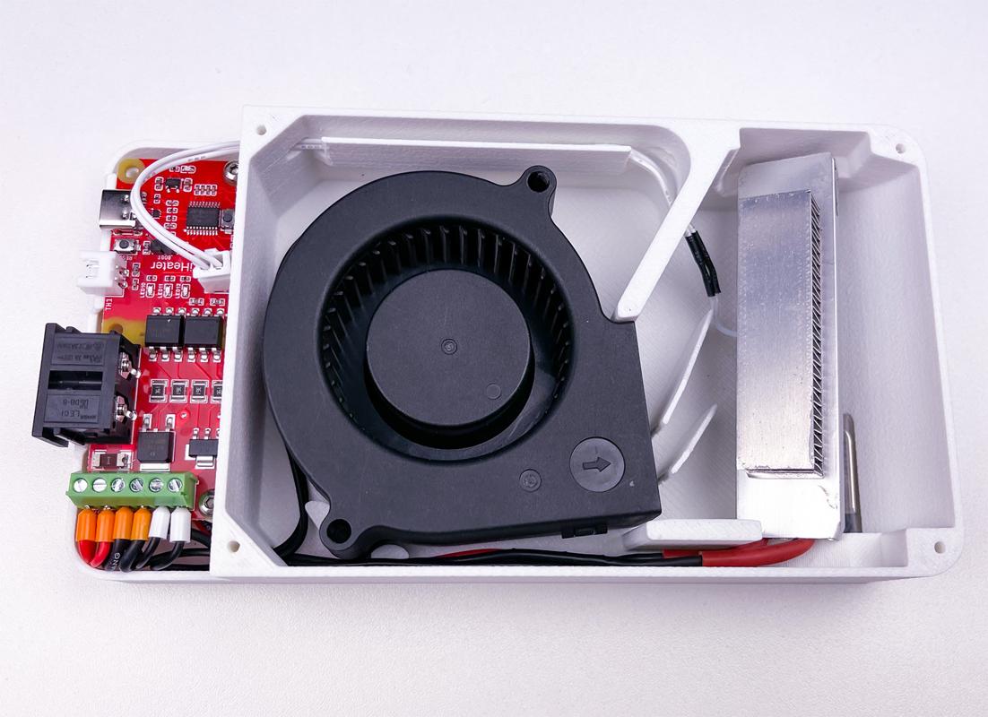
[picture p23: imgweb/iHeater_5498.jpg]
iHeater Assembly


### Final Assembly

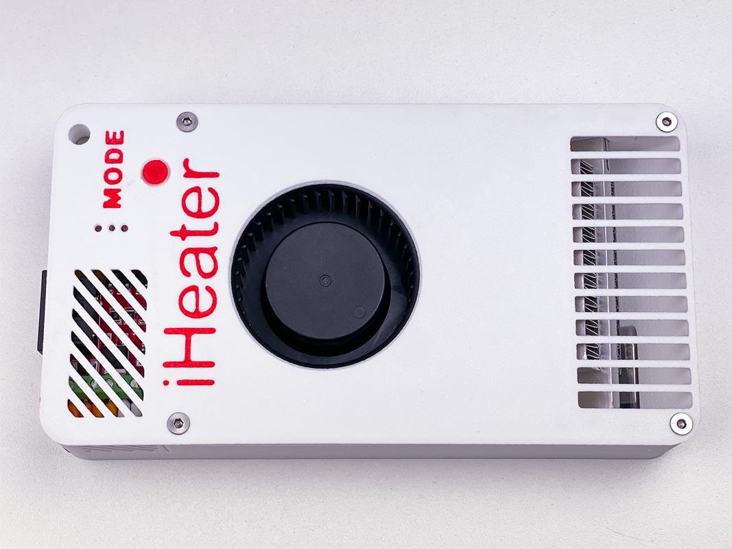
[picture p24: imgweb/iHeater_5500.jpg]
iHeater Assembly


### Finished Product

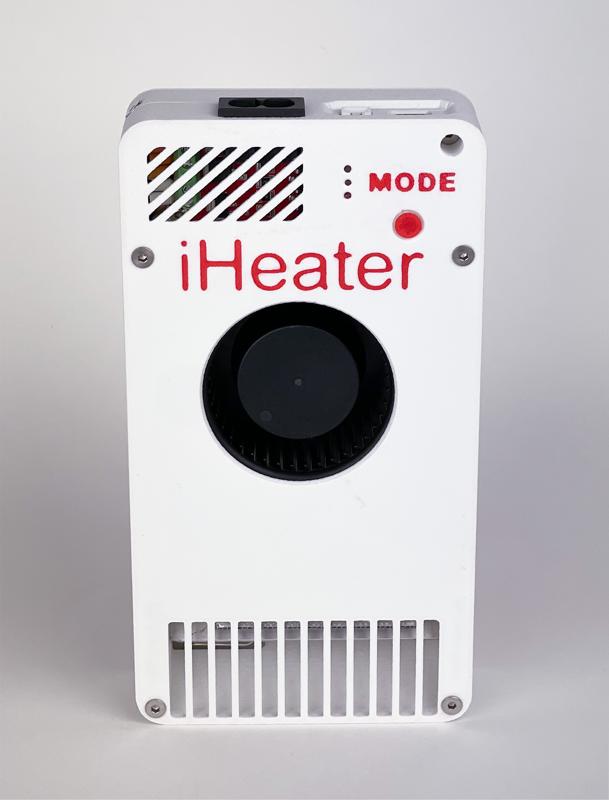
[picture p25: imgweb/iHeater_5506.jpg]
iHeater Assembly


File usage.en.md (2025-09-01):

# Heating the Enclosure in a 3D Printer

## 1. Checking Fans and Ventilation Openings

* Newer printer models often include fans that exhaust hot air from the chamber. Before operating, ensure these do not automatically activate when the chamber temperature rises.

* Check for gaps in the printer enclosure and around the door.

* Inspect the case ventilation holes. If the chamber has contact with the electronics compartment and there are open vents, they must be sealed using:

    * regular tape;
    * aluminum tape (better heat reflection);
    * or thermal insulation (best option).

* This prevents the control electronics from overheating.

## 2. Heat Source: Heated Bed

* The heated bed is the primary heat source for the enclosure.
* An iHeater alone usually cannot reach the target temperature without the heat bed.
* If chamber preheating is needed without using the heat bed, use industrial heaters rated at 600W to 1kW to compensate for the missing bed heat (**ensure electrical safety and that the power supply can handle the load**).

## 3. Using Auxiliary Fans

* Modern printers often have extra fans along sidewalls for part cooling or internal carbon filters.
* During chamber preheating, these can be activated to mix air—accelerating and evening out the temperature rise.
* Ideally, implement macro logic: fans activate at the start of heating, and deactivate once the target temperature is reached or the initial print layers begin.

## 4. When to Start Printing

* Example: target chamber temperature is 60°C.
* Printing can begin at 50-55°C, since preparatory steps follow: bed leveling, nozzle heating and cleaning, laying initial layers.
* These steps take several minutes, during which the chamber will approach the target temperature.
* After printing the first 2-3mm of the model, the chamber usually stabilizes at the desired temperature. This behavior varies between printers.

## 5. Installing the Thermistor

* Place the temperature sensor (thermistor) approximately at the hotend level.
* It must not touch any part of the printer's frame to avoid reading surface temperature instead of ambient air temperature.

## 6. Safety and Additional Recommendations

* Position the iHeater to ensure even airflow and avoid localized overheating.
* Apply thermal insulation to the enclosure to reduce heat loss.
* Power lines for heaters must support the current load (cables, connectors, fuses).
* Temperature limits should be appropriate for the printer's enclosure materials and operating conditions.

---

## 7. Quick Pre-Start Checklist

* [ ] Fans are operational; ventilation openings are clear.
* [ ] Electronics compartment is isolated from the heated chamber.
* [ ] An additional heat source has been activated.
* [ ] Air mixing fans activate during preheating.
* [ ] Thermistor installed at hotend level, not touching the frame.
* [ ] Temperature limits and emergency shutdowns are configured.

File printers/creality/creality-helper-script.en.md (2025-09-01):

## Flashing iHeater for Creality Printers via Creality Helper Script

To ensure successful flashing and integration of iHeater, follow the step-by-step guide below:

### 1. Install Creality Helper Script

Go to the Creality Helper Script documentation page and follow the installation instructions.

**Resources:**

* Video guide: [YouTube](https://youtu.be/k9kPcDfBgmo?t=254)
* Text instructions: [guilouz.github.io](https://guilouz.github.io/Creality-Helper-Script-Wiki/firmwares/install-and-update-rooted-firmware-k1/)

### 2. Gain root access to the printer and access the file system

The script will provide access to Mainsail as well as to the firmware configuration files. After successful installation, ensure that you can access the printer's interface via a web browser and access the configuration files.

### 3. Remove old `fan-control.cfg`

On Creality printers with the Helper Script, a `fan-control.cfg` file containing `M141` and `M191` macros may already exist by default. It conflicts with similar macros in the iHeater configuration.

Rename the file:

```
/usr/data/printer_data/config/fan-control.cfg
```

to fan-control.cfg.bak

### 4. Copy the new `fan-control.cfg`

Replace it with the [fan-control.cfg](config/fans-control.cfg) version compatible with the chamber temperature control logic and macros.

Place the new file in the same folder:

```
/usr/data/printer_data/config/fan-control.cfg
```

### 5. Add the iHeater configuration

Copy the `iheater.cfg` file into the same directory:

```
/usr/data/printer_data/config/iheater.cfg
```

Then open `printer.cfg` and add the following line at the end of the file:

```ini
[include iheater.cfg]
```

---

Proceed with the iHeater setup guide - thermistor configuration, heater setup, operating modes, and macros.

!!! warning "If you cannot build and flash firmware on the printer"
    [Refer to the WSL section](./User-mods/software/WSL2_Ubuntu_FF/README.en.md)

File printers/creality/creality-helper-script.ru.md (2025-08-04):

## Прошивка iHeater для принтеров Creality через Creality Helper Script

Чтобы прошивка и интеграция iHeater прошли успешно, следуйте пошаговой инструкции:

### 1. Установите Creality Helper Script

Перейдите на страницу документации проекта Creality Helper Script и следуйте инструкции по установке скрипта.

**Ресурсы:**

* Видеоруководство: [YouTube](https://youtu.be/k9kPcDfBgmo?t=254)
* Текстовая инструкция: [guilouz.github.io](https://guilouz.github.io/Creality-Helper-Script-Wiki/firmwares/install-and-update-rooted-firmware-k1/)

### 2. Получите root-доступ к принтеру и доступ к файловой системе

Скрипт откроет доступ к Mainsail, а также к файлам конфигурации прошивки. После успешной установки убедитесь, что можете зайти на интерфейс принтера через браузер и получить доступ к файлам конфигурации.

### 3. Удалите старый `fan-control.cfg`

На принтерах Creality с Helper Script по умолчанию уже может быть создан файл `fan-control.cfg` с макросами `M141` и `M191`. Он конфликтует с аналогичными макросам в конфигурации iHeater.

Переименуйте файл:

```
/usr/data/printer_data/config/fan-control.cfg
```
в fan-control.cfg.bak

### 4. Скопируйте новый `fan-control.cfg`

Замените его на версию [fan-control.cfg](config/fans-control.cfg), совместимую с макросами и логикой управления температурой камеры.

Поместите новый файл в ту же папку:

```
/usr/data/printer_data/config/fan-control.cfg
```

### 5. Добавьте конфигурацию iHeater

Скопируйте файл `iheater.cfg` в ту же директорию:

```
/usr/data/printer_data/config/iheater.cfg
```

Затем откройте `printer.cfg` и в конце файла добавьте строку:

```ini
[include iheater.cfg]
```

---

Далее следуйте инструкции по настройке iHeater - настройка термистора, нагревателя, режимов работы и макросов.

!!! warning "Если нет возможности собрать и прошить прошивку на принтере"
    [Обратитесь к разделу WSL](../../User-mods/software/WSL2_Ubuntu_FF/README.ru.md)

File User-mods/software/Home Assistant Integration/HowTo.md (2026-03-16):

# iHeater Integration via Klipper and Home Assistant

This guide explains how to run the **iHeater** as a standalone Klipper MCU (without a printer mainboard) and control the chamber temperature via **Home Assistant** based on the active print material.

The setup uses:

- **Klipper** running on a Raspberry Pi
- **Moonraker** as API layer
- **Mainsail** for Klipper management
- **Home Assistant** for automation and material-based temperature control

The repository already contains the required configuration files:

- `printer.cfg`
- `iHeater.cfg`

# Prerequisites

Before starting, ensure you have:

- Raspberry Pi (recommended: Pi 3 or newer)
- Raspberry Pi OS or OS Lite (64-bit)
- iHeater board
- USB cable
- Home Assistant instance
- Network access between Home Assistant and the Raspberry Pi

## 1. Raspberry Pi Setup with KIAUH

1. Flash **Raspberry Pi OS (Lite) 64-bit** to an SD card.
2. Boot the Pi, connect via SSH, and install KIAUH:
   ```bash
   sudo apt-get update && sudo apt-get install git -y
   git clone https://github.com/dw-0/kiauh.git
   ./kiauh/kiauh.sh
   ```
3. Use the KIAUH menu to install:
   - **1) Klipper**
   - **2) Moonraker**
   - **3) Mainsail**

## 2. Configure Klipper Firmware

Compile the firmware for the STM32F042 microcontroller.

1. Connect the iHeater to a USB port of your Raspberry Pi.
   Verify that the device is detected:
   ```bash
   ls /dev/serial/by-id/
   ```
   You should see a device similar to:
   ```bash
   /dev/serial/by-id/usb-Klipper_stm32f042...
   ```
   
2. Compile Klipper Firmware
    Navigate to the Klipper directory:
   ```bash
   cd ~/klipper
   make menuconfig
   ```
3. Configure the firmware according to the official iHeater documentation:
   https://github.com/zanex88/iHeater/blob/main/flashing.en.md

## 3. Flash STM32 Firmware

1. See [Flashing Firmware](https://github.com/zanex88/iHeater/blob/main/flashing.en.md)
2. Retrieve the serial path for the Klipper configuration:
   ```bash
   ls /dev/serial/by-id/
   ```
   *Copy the output string (e.g., `/dev/serial/by-id/usb-Klipper_stm32f042...`).*

## 4. Adjust Klipper Configs

Open the Mainsail web interface (via the Pi's IP address) and edit the configuration files (Menu left side "Machine").
Upload the configuration files from this repository. USE your MCU serial in printer.cfg.
* `printer.cfg`
* `iHeater.cfg`

Save and click **FIRMWARE RESTART**.

## 5. Home Assistant Integration

1. In Home Assistant, go to **Settings -> Devices & Services -> Add Integration**.
2. Search for **Moonraker** and enter the IP address of your Raspberry Pi (default port: 7125).
3. **Important:** The default `climate` entity exposed by Moonraker controls the hardware heater block (`iHeater_H`), not the chamber temperature macro. To control the chamber properly via `M141`, add a REST command to your `configuration.yaml`:

```yaml
rest_command:
  iheater_set_temp:
    url: "http://<IP_OF_YOUR_PI>:7125/printer/gcode/script"
    method: POST
    payload: '{"script": "M141 S{{ temp }}"}'
    content_type: "application/json"
```
*Restart Home Assistant after adding this.*

4. Create a Number Helper (`input_number.setpoint_iheater`) in Home Assistant to set the target temperature manually or via automations.

## 6. Home Assistant Automation 

This automation controls the iHeater automatically based on the Bambu Lab bed target temperature and the active material slot. 

* **Trigger:** Bed target temperature changes.
* **Logic:** * If Bed > 0: Checks the material string. If unknown/empty, sets a 35°C pre-heat. Once the material is identified, it applies the specific temperature.
  * If Bed = 0: Shuts down the iHeater.

```yaml
alias: "iHeater: Auto-Start & Material-Update"
mode: restart
trigger:
  - platform: state
    entity_id: number.p1s_01p09c541801823_zieltemperatur_des_druckbett
  - platform: state
    entity_id: sensor.p1s_01p09c541801823_aktiver_slot
action:
  - action: input_number.set_value
    target:
      entity_id: input_number.setpoint_iheater
    data:
      value: >
        {% set bed_target = states('number.p1s_01p09c541801823_zieltemperatur_des_druckbett') | float(0) %}
        {% set mat = states('sensor.p1s_01p09c541801823_aktiver_slot') | lower %}
        
        {% if bed_target > 0 %}
          {% if 'pla' in mat %}
            30
          {% elif 'petg' in mat %}
            45
          {% elif 'abs' in mat or 'asa' in mat %}
            65
          {% elif 'pa' in mat or 'nylon' in mat %}
            65
          {% elif 'pc' in mat %}
            75
          {% elif 'tpu' in mat %}
            0
          {% else %}
            35
          {% endif %}
        {% else %}
          0
        {% endif %}
  - action: rest_command.iheater_set_temp
    data:
      temp: "{{ states('input_number.setpoint_iheater') | int }}"
```
*(Ensure to replace the entity IDs with your actual Bambu Lab integration entity IDs).*

This automation controls the iHeater based on the change of the helper entity e.g. by using a slider

```yaml
alias: "iHeater: Send setpoint to Klipper"
description: ""
triggers:
  - entity_id: input_number.setpoint_iheater
    trigger: state
actions:
  - action: rest_command.iheater_set_temp
    data:
      temp: "{{ trigger.to_state.state | int }}"
mode: single
```
*(Ensure to replace the entity IDs with your actual Bambu Lab integration entity IDs).*

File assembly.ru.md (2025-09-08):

## Сборка

# Перед сборкой¶

## Документация
Ознакомьтесь с документацией, скачайте и распечатайте необходимые детали. Удостоверьтесь в наличии необходимых деталей и инструментов.

## Приступая к сборке

Рекомендуется сначала собрать всю систему **на столе**, без монтажа в корпус, и провести тестирование:

- Подключить **все** компоненты.
- Проверить работоспособность нагревателя, вентилятора, датчиков температуры.
- Подключить систему к **Klipper** или прошить standalone прошивкой и убедиться в корректной работе макросов.

Video guide: [YouTube](https://youtu.be/1QMtVY0Vx-8?si=Ol1u4Ux9wALDcfe2)

### Установка платы
Сборка iHeater

### Установка Термистора и KSD

!!! warning "Установка термистора"
    Убедитесь, что провода термистора не соприкасаются с металлическим корпусом нагревателя. Если есть сомнения, термистор следует заизолировать - например, обмотать каптоновым скотчем или поместить в любой термостойкий изолирующий материал (например, тефлоновую трубку или термоусадочную изоляцию).

    Помните, температура нагревателя может достигать 140С

!!! warning "Установка термопредохранителя"
    Вы можете установить либо самовосстанавливающийся термовыключатель, такой как KSD9700, либо плавкий термопредохранитель.

    Имейте в виду, что плавкий предохранитель — это одноразовое защитное устройство: при превышении температуры он навсегда разрывает цепь, и для восстановления потребуется его замена на аналогичный.

    В свою очередь, KSD9700 представляет собой биметаллический термовыключатель. Он размыкает цепь при достижении заданной температуры и автоматически замыкает её обратно, когда температура опускается ниже установленного порога. Это позволяет системе восстановить работу без замены компонента.

    С точки зрения безопасности, плавкий предохранитель обеспечивает более надёжную защиту, поскольку исключает повторное включение в случае неисправности или перегрева.

    Поскольку это DIY-проект, и работа с нагревательными элементами требует понимания принципов электрической безопасности, если вы не уверены в своих действиях, рекомендуется сначала настроить систему с использованием KSD9700 (для тестирования и отладки), а затем заменить его на соответствующий плавкий предохранитель.

Сборка iHeater
Сборка iHeater

### Установка нагревателя
Сборка iHeater

### Проводка
Сборка iHeater

### Установка НШВИ
Сборка iHeater

### Коммутация
Сборка iHeater

### Финальная сборка
Сборка iHeater

### Готовое изделие
Сборка iHeater

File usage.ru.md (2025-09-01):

# Нагрев термокамеры в 3D‑принтере

## 1. Проверка вентиляторов и вентиляционных отверстий

* В новых моделях принтеров часто устанавливаются вентиляторы для выдува горячего воздуха из камеры. Перед началом эксплуатации убедитесь, что они не включаются автоматически при превышении температуры в камере..
* Проверьте щели в корпусе принтера и вокруг двери
* Проверьте вентиляционные отверстия корпуса. Если камера имеет контакт с отсеком электроники, и там есть незакрытые отверстия, их необходимо закрыть:

    * обычным скотчем;
    * алюминиевым скотчем (лучше отражает тепло);
    * либо теплоизоляцией (лучший вариант).
* Это нужно для того, чтобы управляющая электроника не перегревалась.

## 2. Источник тепла: стол принтера

* Нагревательный стол - главный источник тепла для камеры.
* Сам по себе iHeater обычно не поднимет температуру до требуемой без стола.
* Если требуется прогрев объёма принтера без включенного стола, используйте нагреватели фабричного производства мощностью 600Вт - 1кВт, чтобы компенсировать отсутствие тепла от стола (**с проверкой электробезопасности и нагрузочной способности цепей питания**).

## 3. Использование вспомогательных кулеров

* В современных моделях часто есть дополнительные вентиляторы вдоль боковых стенок, предназначенные для дополнительного обдува модели или угольные фильтры внутри камеры.
* На этапе нагрева камеры их можно включать для перемешивания воздуха - это ускоряет и выравнивает прогрев.
* Оптимально предусмотреть макро‑логику: при старте нагрева кулеры включаются, после достижения целевой температуры или стартовых слоев печати - отключаются.

## 4. Когда начинать печать

* Пример: целевая температура камеры - 60°C.
* Печать можно начинать с 50-55°C, потому что перед стартом есть подготовительные операции: построение карты стола, прогрев и очистка сопла, укладка первых слоёв.
* Эти процессы занимают несколько минут; за это время камера успевает приблизиться к целевому значению.
* После печати первых 2-3мм модели камера обычно достигает нужной температуры и стабилизируется, этот параметр индивидуально для каждого принтера

## 5. Установка термистора

* Термодатчик (термистор) размещайте примерно на уровне печатающей головы.
* Он не должен касаться деталей корпуса принтера, иначе будет считывать их температуру, а не температуру воздуха.

## 6. Безопасность и доп. рекомендации

* Располагайте iHeater так, чтобы обеспечивать равномерный поток и исключать локальные перегревы.
* Применяйте теплоизоляцию корпуса для снижения теплопотерь.
* Линии питания нагревателей должны выдерживать токовую нагрузку (кабель, разъёмы, предохранитель).
* Температурные режимы соответствовать материалам корпуса принтера и условиям эксплуатации.

---

## 7. Короткий чек‑лист перед запуском

* [ ] Вентиляторы исправны; вентиляционные отверстия очищены.
* [ ] Отсек электроники изолирован от горячего объёма камеры.
* [ ] Включен дополнительный источник тепла.
* [ ] Кулеры для перемешивания воздуха активируются на этапе прогрева.
* [ ] Термодатчик установлен на уровне печатающей головы, не касается корпуса.
* [ ] Лимиты температуры и аварийные отключения настроены.

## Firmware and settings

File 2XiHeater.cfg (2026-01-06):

#========================================================
#=====================iHeater cfg========================
#========================================================

#========================================================
# MCU & PINS - LEFT HEATER
#========================================================
[mcu iHeater_left]
serial: ## add your own: /dev/serial/by-id/usb-Klipper_stm32f042x6_1234567899ABCDEF0123458F-if00
restart_method: command

[board_pins iHeater_left_Aliases]
mcu: iHeater_left
aliases:
    TH0=PA3, TH1=PA0, TH2=PB1,
    HEATER=PA1, FAN=PA2,
    MODE=PA4,
    LED_HEATER_ON=PA7,   # Rightmost LED (Heating element)
    LED_TARGET_SET=PA6,  # Center LED (Target set)
    LED_FAN_ON=PA5,      # Leftmost LED (Fan active)
    USART1_TX=PA9, USART1_RX=PA10
    
#========================================================
# MCU & PINS - RIGHT HEATER
#========================================================
[mcu iHeater_right]
serial: ## add your own: /dev/serial/by-id/usb-Klipper_stm32f042x6_22222-if00
restart_method: command

[board_pins iHeater_right_Aliases]
mcu: iHeater_right
aliases:
    TH0=PA3, TH1=PA0, TH2=PB1,
    HEATER=PA1, FAN=PA2,
    MODE=PA4,
    LED_HEATER_ON=PA7,   # Rightmost LED (Heating element)
    LED_TARGET_SET=PA6,  # Center LED (Target set)
    LED_FAN_ON=PA5,      # Leftmost LED (Fan active)
    USART1_TX=PA9, USART1_RX=PA10

#============================================================
#================== iHeater CONFIG - LEFT ===================
#============================================================

[heater_generic iHeater_left_H]
heater_pin: iHeater_left:HEATER
max_power: 1
sensor_type: NTC 100K MGB18-104F39050L32
sensor_pin: iHeater_left:TH0
pwm_cycle_time: 0.3
min_temp: 0
max_temp: 120
control: pid
pid_Kp: 37.948
pid_Ki: 2.040
pid_Kd: 176.497

[verify_heater iHeater_left_H]
max_error: 120                
check_gain_time: 60           
hysteresis: 20               
heating_gain: 0.2 

[heater_fan chamber_heater_fan_left]
pin: iHeater_left:FAN
heater: iHeater_left_H
heater_temp: 50.0
fan_speed: 1.0
shutdown_speed: 0
kick_start_time: 0.5

[temperature_sensor iHeater_back_S]
sensor_pin: iHeater_left:TH1
sensor_type: NTC 100K MGB18-104F39050L32
min_temp: 0
max_temp: 140

# Define all LEDs as [output_pin] for macro control
[output_pin iHeater_L_Heater_On]
pin: iHeater_left:LED_HEATER_ON

[output_pin iHeater_L_Target_Set]
pin: iHeater_left:LED_TARGET_SET

[output_pin iHeater_L_Fan_On]
pin: iHeater_left:LED_FAN_ON

[gcode_button mode_button_left]
pin: iHeater_left:MODE
# debounce_delay: 50
press_gcode: iHEATER_OFF

#============================================================
#================== iHeater CONFIG - RIGHT ==================
#============================================================

[heater_generic iHeater_right_H]
heater_pin: iHeater_right:HEATER
max_power: 1
sensor_type: NTC 100K MGB18-104F39050L32
sensor_pin: iHeater_right:TH0
pwm_cycle_time: 0.3
min_temp: 0
max_temp: 120
control: pid
pid_Kp: 37.948
pid_Ki: 2.040
pid_Kd: 176.497

[verify_heater iHeater_right_H]
max_error: 120                
check_gain_time: 60           
hysteresis: 20               
heating_gain: 0.2 

[heater_fan chamber_heater_fan_right]
pin: iHeater_right:FAN
heater: iHeater_right_H
heater_temp: 50.0
fan_speed: 1.0
shutdown_speed: 0
kick_start_time: 0.5

[temperature_sensor iHeater_gantry_S]
sensor_pin: iHeater_right:TH1
sensor_type: NTC 100K MGB18-104F39050L32
min_temp: 0
max_temp: 140

[gcode_button mode_button]
pin: iHeater_right:MODE
# debounce_delay: 50
press_gcode: iHEATER_OFF

# Define all LEDs as [output_pin] for macro control
[output_pin iHeater_R_Heater_On]
pin: iHeater_right:LED_HEATER_ON

[output_pin iHeater_R_Target_Set]
pin: iHeater_right:LED_TARGET_SET

[output_pin iHeater_R_Fan_On]
pin: iHeater_right:LED_FAN_ON


#######################################################
################## DUAL HEATER SETUP ##################
#######################################################

[temperature_sensor Chamber]
sensor_type: temperature_combined
sensor_list: temperature_sensor iHeater_gantry_S, temperature_sensor iHeater_gantry_S, temperature_sensor iHeater_back_S    # 2:1 weighted average
combination_method: mean
min_temp: 0
max_temp: 140
maximum_deviation: 20

[gcode_macro CHAMBER_VARS]
variable_chamber_target: 0
variable_bed_target: 0
variable_start_offset: 10
variable_delta_temp: 10
variable_min_heater_temp: 50
variable_max_heater_temp: 90
variable_control_interval: 1.0
variable_air_min_delta: 0.5
variable_air_max_delta: 5.0
variable_verify_ac_power_delay: 60  # grace period seconds
variable_min_heater_delta: 5        # heater temp needs to rise above chamber temp by this amount if power > 90% °C
variable_heat_start_time: 0         # Do not change
variable_ac_power_verified: False 
gcode:

#######################################################
#################### REVISED MACROS ###################
#######################################################

[gcode_macro M141]
gcode:
    {% set chamber_target = params.S|default(printer["gcode_macro CHAMBER_VARS"].chamber_target)|int %}
    {% set delta_temp = params.D|default(printer["gcode_macro CHAMBER_VARS"].delta_temp)|int %}
    {% set max_heater_temp = params.H|default(printer["gcode_macro CHAMBER_VARS"].max_heater_temp)|int %}
    {% set control_interval = printer["gcode_macro CHAMBER_VARS"].control_interval|float %}

    RESPOND prefix="M141" msg="S{chamber_target} D{delta_temp} H{max_heater_temp}"

    SET_GCODE_VARIABLE MACRO=CHAMBER_VARS VARIABLE=chamber_target VALUE={chamber_target}
    SET_GCODE_VARIABLE MACRO=CHAMBER_VARS VARIABLE=delta_temp VALUE={delta_temp}
    SET_GCODE_VARIABLE MACRO=CHAMBER_VARS VARIABLE=max_heater_temp VALUE={max_heater_temp}

    # Record the start time of the heating cycle for the AC power check
    SET_GCODE_VARIABLE MACRO=CHAMBER_VARS VARIABLE=heat_start_time VALUE={printer.toolhead.estimated_print_time}
    SET_GCODE_VARIABLE MACRO=CHAMBER_VARS VARIABLE=ac_power_verified VALUE=False

    # Turn on the "Target Set" LED (Center LED)
    SET_PIN PIN=iHeater_L_Target_Set VALUE=1
    SET_PIN PIN=iHeater_R_Target_Set VALUE=1

    iHEATER_CONTROL

[gcode_macro M191]
gcode:
    {% set chamber_target = params.S|default(printer["gcode_macro CHAMBER_VARS"].chamber_target)|int %}
    {% set delta_temp = params.D|default(printer["gcode_macro CHAMBER_VARS"].delta_temp)|int %}
    {% set max_heater_temp = params.H|default(printer["gcode_macro CHAMBER_VARS"].max_heater_temp)|int %}
    {% set start_offset = params.W|default(printer["gcode_macro CHAMBER_VARS"].start_offset)|int %}
    
    RESPOND prefix="M191" msg="S{chamber_target} D{delta_temp} H{max_heater_temp} W{start_offset}"

    M141 S{chamber_target} D{delta_temp} H{max_heater_temp}
    SET_GCODE_VARIABLE MACRO=CHAMBER_VARS VARIABLE=start_offset VALUE={start_offset}

    # MODIFIED: Wait until BOTH chamber sensors reach the target temperature
    {% set min_temp_to_wait = chamber_target - start_offset %}
    RESPOND prefix="M191" msg="Waiting for chamber to reach {min_temp_to_wait}°C..."
    #TEMPERATURE_WAIT SENSOR="temperature_sensor iHeater_back_S" MINIMUM={min_temp_to_wait}
    #TEMPERATURE_WAIT SENSOR="temperature_sensor iHeater_gantry_S" MINIMUM={min_temp_to_wait}
    TEMPERATURE_WAIT SENSOR="temperature_sensor Chamber" MINIMUM={min_temp_to_wait}
    RESPOND prefix="M191" msg="Chamber reached {min_temp_to_wait}°C"

[gcode_macro iHEATER_ON]
description: Alternative to M141 & M191 with alternative parameter names
gcode:
    {% set s = params.CHAMBER_TEMP|default(0)|int %}
    {% set b = params.BED_TEMP|default(0)|int %}
    {% set d = params.DELTA|default(10)|int %}
    {% set h = params.HEATER_MAX|default(90)|int %}
    {% set w = params.CHAMBER_AWAIT_TEMP|default(10)|int %}

    {% if b > 0 and b<110 %}
        SET_HEATER_TEMPERATURE HEATER=heater_bed TARGET={b}
    {% endif %}

    {% if w > 0 %}
        M191 S{s} D{d} H{h} W{s - w}
    {% else %}
        M141 S{s} D{d} H{h}
    {% endif %}

[gcode_macro iHEATER_OFF]
gcode:
    # Set target temp to 0 and turn off heaters
    SET_GCODE_VARIABLE MACRO=CHAMBER_VARS VARIABLE=chamber_target VALUE=0
    SET_HEATER_TEMPERATURE HEATER=iHeater_left_H TARGET=0
    SET_HEATER_TEMPERATURE HEATER=iHeater_right_H TARGET=0

     # Reset the AC verify timer
    SET_GCODE_VARIABLE MACRO=CHAMBER_VARS VARIABLE=heat_start_time VALUE=0
    SET_GCODE_VARIABLE MACRO=CHAMBER_VARS VARIABLE=ac_power_verified VALUE=False

    # Immediately turn off ALL LEDs for a clean shutdown
    SET_PIN PIN=iHeater_L_Target_Set VALUE=0
    SET_PIN PIN=iHeater_R_Target_Set VALUE=0
    SET_PIN PIN=iHeater_L_Heater_On VALUE=0
    SET_PIN PIN=iHeater_R_Heater_On VALUE=0
    SET_PIN PIN=iHeater_L_Fan_On VALUE=0
    SET_PIN PIN=iHeater_R_Fan_On VALUE=0

    # Run one last cycle to handle cooldown
    UPDATE_DELAYED_GCODE ID=_iHEATER_CONTROL DURATION=1
    RESPOND prefix="iHeater_off" msg="Heating disabled for both heaters."
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

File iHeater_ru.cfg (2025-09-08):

#========================================================
#=====================iHeater cfg========================
#========================================================

#=====================iHeater pins=======================
[board_pins iHeater_Aliases]
mcu: iHeater
aliases:
    TH0=PA3, TH1=PA0, TH2=PB1,
    HEATER=PA1, FAN=PA2,
    MODE=PA4,
    LED1=PA7, LED2=PA6, LED3=PA5,
    USART1_TX=PA9, USART1_RX=PA10

#=====================iHeater mcu=======================
# [mcu]
# serial: /dev/serial/by-id/usb-Klipper_stm32f042x6_0C0018000D53304347373020-if00

[mcu iHeater] #second MCU
#is_non_critical: true: true # flag this as non critical
serial: /dev/serial/by-id/usb-Klipper_stm32f042x6_430018000E53304347373020-if01
restart_method: command

#============================================================
#======================= iHeater CONFIG =====================
#============================================================

# Make sure to perform PID calibration for the chamber heater:
#🔥🔥🔥🔥🔥🔥🔥🔥🔥🔥🔥🔥🔥🔥🔥🔥🔥🔥🔥🔥🔥🔥🔥🔥🔥🔥🔥
#  PID_CALIBRATE HEATER=iHeater_H TARGET=70
#🔥🔥🔥🔥🔥🔥🔥🔥🔥🔥🔥🔥🔥🔥🔥🔥🔥🔥🔥🔥🔥🔥🔥🔥🔥🔥🔥
# This is essential for accurate and stable chamber heating.
# Without PID tuning, the temperature may overshoot or take too long to stabilize!

#===========================================================

[heater_generic iHeater_H]
heater_pin: iHeater:HEATER
max_power: 1
sensor_type: NTC 100K MGB18-104F39050L32
sensor_pin: iHeater:TH0
pwm_cycle_time: 0.3
min_temp: 0
max_temp: 120
control: pid
pid_Kp: 37.948
pid_Ki: 2.040
pid_Kd: 176.497

[verify_heater iHeater_H]
max_error: 240
check_gain_time: 1800
heating_gain: 1

[heater_fan chamber_heater_fan]
pin: iHeater:FAN
heater: iHeater_H
heater_temp: 50.0
fan_speed: 1.0
shutdown_speed: 0
kick_start_time: 0.5

[temperature_sensor iHeater_S]
sensor_pin: iHeater:TH1
sensor_type: NTC 100K MGB18-104F39050L32
min_temp: 0
max_temp: 140

# [temperature_sensor iHeater_Chamber_ext]
# sensor_pin: iHeater:TH2
# sensor_type: NTC 100K MGB18-104F39050L32
# min_temp: 0
# max_temp: 140

[gcode_button mode_button]
pin: iHeater:MODE
# debounce_delay: 50
press_gcode: iHEATER_OFF

[output_pin led_1]
pin: iHeater:LED1

[output_pin led_2]
pin: iHeater:LED2

[output_pin led_3]
pin: iHeater:LED3

#######################################################
##########################SETUP########################
#######################################################

[gcode_macro CHAMBER_VARS]
variable_chamber_target: 0          # целевая температура камеры, °C
variable_chamber_await_target: 0    # допустимая для начала печати температура камеры, °C
variable_delta_temp: 10             # дельта между камерой и нагревателем, °C
variable_min_heater_temp: 50        # минимальная температура нагревателя (для охлаждения), °C
variable_max_heater_temp: 100       # максимальная температура нагревателя, °C
variable_control_interval: 1.0      # интервал вызова функции управления, секунды
variable_air_min_delta: 0.5         # минимальная разница между желаемой и текущей температурой камеры (температура нагревателя равна желаемой температуре + delta_temp), °C
variable_air_max_delta: 5.0         # максимальная разница между желаемой и текущей температурой камеры (температура нагревателя равна max_heater_temp), °C
gcode:

##########################MACRO########################

[gcode_macro M141]
#rename_existing: M141.1
gcode:
    # Получаем желаемую температуру камеры: 
    # - если передан параметр S - используем его
    # - иначе берём значение chamber_target из CHAMBER_VARS
    {% set chamber_target = params.S|default(printer["gcode_macro CHAMBER_VARS"].chamber_target)|int %}
    # Получаем значение температурной дельты:
    # - если передан параметр D - используем его
    # - иначе берём значение delta_temp из CHAMBER_VARS
    {% set delta_temp = params.D|default(printer["gcode_macro CHAMBER_VARS"].delta_temp)|int %}
    # Получаем максимальную температуру нагревателя:
    # - если передан параметр H - используем его
    # - иначе берём значение max_heater_temp из CHAMBER_VARS
    {% set max_heater_temp = params.H|default(printer["gcode_macro CHAMBER_VARS"].max_heater_temp)|int %}
    # Получаем интервал для вызова функции управления
    {% set control_interval = printer["gcode_macro CHAMBER_VARS"].control_interval|float %}

    RESPOND prefix="M141" msg="S{chamber_target} D{delta_temp} H{max_heater_temp}"

    # Сохраняем параметры в CHAMBER_VARS для delayed_gcode
    SET_GCODE_VARIABLE MACRO=CHAMBER_VARS VARIABLE=chamber_target VALUE={chamber_target}
    SET_GCODE_VARIABLE MACRO=CHAMBER_VARS VARIABLE=delta_temp VALUE={delta_temp}
    SET_GCODE_VARIABLE MACRO=CHAMBER_VARS VARIABLE=max_heater_temp VALUE={max_heater_temp}

    # Первоначальный расчет
    iHEATER_CONTROL

    # Запускаем макрос контроля температуры
    UPDATE_DELAYED_GCODE ID=_iHEATER_CONTROL DURATION={control_interval}


[gcode_macro M191]
#rename_existing: M191.1
gcode:
    # Получаем желаемую температуру камеры: 
    # - если передан параметр S - используем его
    # - иначе берём значение chamber_target из CHAMBER_VARS
    {% set chamber_target = params.S|default(printer["gcode_macro CHAMBER_VARS"].chamber_target)|int %}
    # Получаем значение температурной дельты:
    # - если передан параметр D - используем его
    # - иначе берём значение delta_temp из CHAMBER_VARS
    {% set delta_temp = params.D|default(printer["gcode_macro CHAMBER_VARS"].delta_temp)|int %}
    # Получаем максимальную температуру нагревателя:
    # - если передан параметр H - используем его
    # - иначе берём значение max_heater_temp из CHAMBER_VARS
    {% set max_heater_temp = params.H|default(printer["gcode_macro CHAMBER_VARS"].max_heater_temp)|int %}
    # Получаем минимальную температуру камеры для начала печати:
    # - если передан параметр W - используем его
    # - иначе берём значение chamber_await_target из CHAMBER_VARS
    {% set chamber_await_target = params.W|default(printer["gcode_macro CHAMBER_VARS"].chamber_await_target)|int %}
    
    RESPOND prefix="M191" msg="S{chamber_target} D{delta_temp} H{max_heater_temp} W{chamber_await_target}"

    M141 S{chamber_target} D{delta_temp} H{max_heater_temp}

    # Сохраняем параметер в CHAMBER_VARS
    SET_GCODE_VARIABLE MACRO=CHAMBER_VARS VARIABLE=chamber_await_target VALUE={chamber_await_target}

    # Ждём, пока камера достигнет заданной температуры
    TEMPERATURE_WAIT SENSOR="temperature_sensor iHeater_S" MINIMUM={chamber_target - chamber_await_target}
    RESPOND prefix="M191" msg="Камера достигла температуры {chamber_await_target}°C"


[gcode_macro iHEATER_ON]
description: Альтернатива командам M141 & M191 с альтернативными именами параметров
gcode:
    {% set s = params.CHAMBER_TEMP|default(printer["gcode_macro CHAMBER_VARS"].chamber_target)|int %}
    {% set d = params.DELTA|default(printer["gcode_macro CHAMBER_VARS"].delta_temp)|int %}
    {% set h = params.HEATER_MAX|default(printer["gcode_macro CHAMBER_VARS"].max_heater_temp)|int %}
    {% set w = params.CHAMBER_AWAIT_TEMP|default(printer["gcode_macro CHAMBER_VARS"].chamber_await_target)|int %}

    {% if w > 0 %}
        # Если параметр w больше 0, то используем M191 с ожиданием достижения минимальной температуры для печати
        M191 S{s} D{d} H{h} W{w}
    {% else %}
        # Иначе используем M141 без ожидания достижения минимальной температуры камеры
        M141 S{s} D{d} H{h}
    {% endif %}


[gcode_macro iHEATER_OFF]
gcode:
    SET_GCODE_VARIABLE MACRO=CHAMBER_VARS VARIABLE=chamber_target VALUE=0
    SET_GCODE_VARIABLE MACRO=CHAMBER_VARS VARIABLE=chamber_await_target VALUE=0

    UPDATE_DELAYED_GCODE ID=_iHEATER_CONTROL DURATION=1
    RESPOND prefix="iHeater_off" msg="Нагрев отключён."
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

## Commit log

2025-04-29 add 200W CAD files, minor updates
    [Base200W.stl, TopCover200W.stl, TopCover200WtwoColor.stl]
2025-08-09 #is_non_critical: true removed
    [iHeater.cfg, iHeater_CREALITY.cfg, iHeater_ru.cfg]
2025-09-01 r1.1 CAD upd
    [iHeater_Base_200W_r1.1.stl, iHeater_Top_Cover_200W_r1.1.stl, iHeater_Top_Cover_200W_r1.1_color.stl]
2025-09-08 iHeater_Chamber_ext commented
    [iHeater.cfg, iHeater_ru.cfg]
2025-09-27 Create 2XiHeater.cfg
    Controls two iHeaters in tandem to achieve a target chamber temperature, adding smart LED controls:
    LEFT: Fan status
    CENTER: Target temperature set
    RIGHT: Heater active (power >30%)
    [2XiHeater.cfg]
2025-09-28 Create 2XiHeater.cfg
    Controls two iHeaters in tandem to achieve a target chamber temperature, adding smart LED controls
    [2XiHeater.cfg]
